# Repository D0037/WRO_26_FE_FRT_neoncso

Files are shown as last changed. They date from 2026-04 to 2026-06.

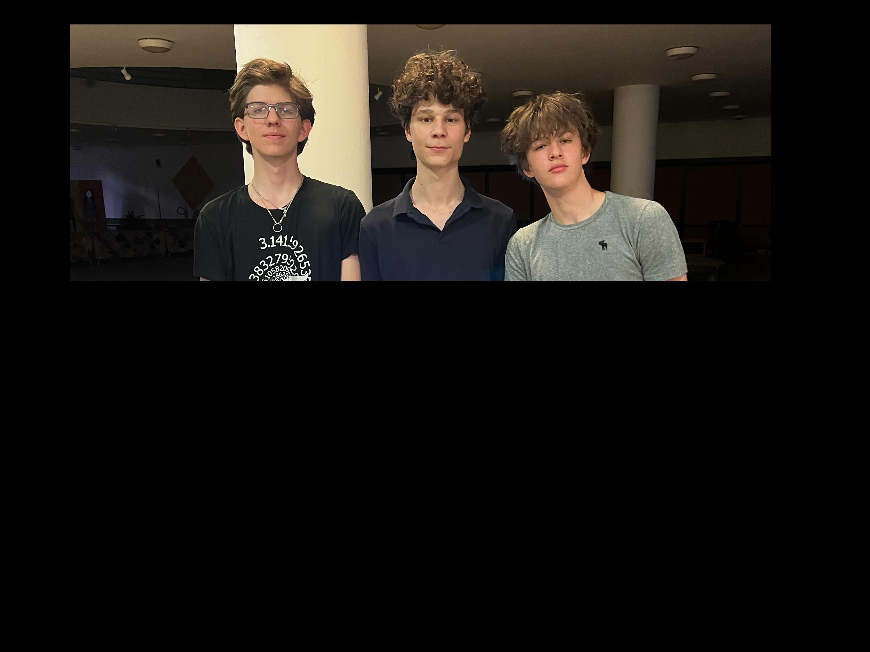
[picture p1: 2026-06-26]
t-photos/Serious.jpg

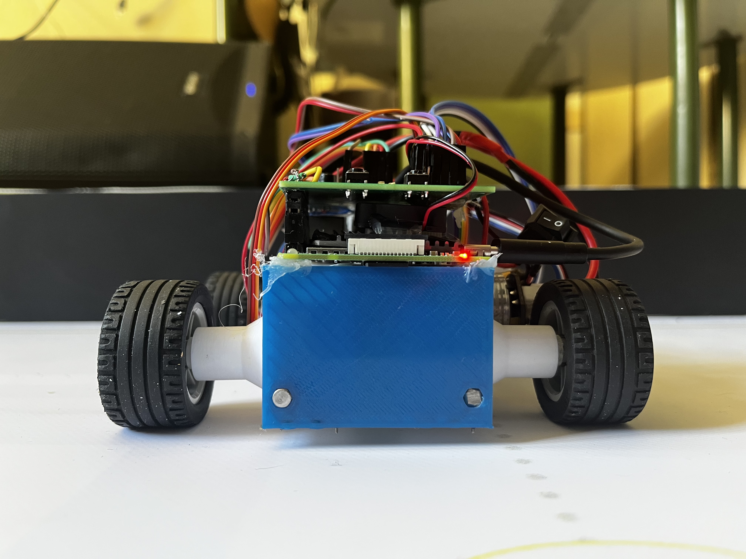
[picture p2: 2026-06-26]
v-photos/back.jpeg

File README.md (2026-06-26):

# FRT Neoncső
## WRO Future Engineers 2026

---

# Team Information

## Team Details

| Item | Information |
|---|---|
| Team Name | FRT Neoncső |
| Country | Hungary |
| School | Budapest Fazekas Mihály Practising Primary and Secondary School |
| Coach | Sásdi Mariann |

## Team Members

| Role | Name | Age |
|---|---|---:|
| Software, electronics, 3D design | Márton Serényi | 16 |
| 3D design, documentation | Ivan Probojcsevity | 16 |
| Software, hardware | Levente Zempléni | 16 |

---

# Project Overview

This project focuses on designing, building, and programming an autonomous vehicle capable of completing the complex challenges of the WRO Future Engineers category.

Team FRT was driven by the challenge of translating engineering principles and problem-solving into practice, and of building a reliable, predictable system in a competition environment full of uncertain variables. Throughout development we followed a systematic process: brainstorming, research, prototyping, testing, and iteration.

_neoncso_ is a **Raspberry Pi**–based, rear-wheel-drive vehicle with Ackermann steering and encoder-based odometry. Its navigation relies on two complementary sensing layers: an **inertial measurement unit (IMU)** holds the heading through a PID controller, three **VL53L1X ToF sensors** measure the distance to the walls, and a **camera** identifies the red and green traffic markers and the parking zone using OpenCV-based HSV color detection.

The control software is built in a modular Python architecture, with separate state machines for the open and obstacle challenges, and a custom web-based HSV calibration tool that lets us quickly retune the vision system to the venue's changing lighting conditions on site.

Our goal is to create an intelligent vehicle that navigates the course reliably, precisely, and quickly, while keeping every decision it makes engineering-based and justifiable.

## Challenge Summary

### 1. Open Challenge

**Goal:** Drive an autonomous car around the track for **3 complete laps** as quickly and accurately as possible. 

Key points:

* No traffic-sign obstacles are placed on the track.
* The track layout changes between rounds because the inner walls can be arranged differently.
* The starting position and driving direction (clockwise or counterclockwise) are randomized.
* The vehicle must:

  * Follow the correct driving direction.
  * Complete 3 laps.
  * Stop in the designated finish section. 
What is tested:

* Lane following
* Cornering accuracy
* Speed and consistency
* Adaptation to changing track layouts

---

### 2. Obstacle Challenge

**Goal:** Complete the same **3 autonomous laps**, but now obey traffic signs and finish with a parking maneuver. 

Additional elements:

* **Red pillar:** pass it on the **right** side.
* **Green pillar:** pass it on the **left** side.
* Traffic signs are placed randomly before each round.
* After finishing the 3 laps, the vehicle must locate the parking area and perform **parallel parking**. 

Scoring rewards:

* Completing laps.
* Not moving traffic signs.
* Starting from the parking lot (optional bonus).
* Successfully parking fully inside the parking area and parallel to the wall. 

What is tested:

* Traffic-sign recognition and decision making.
* Path planning around obstacles.
* Precision vehicle control.
* Autonomous parking.

#### In one sentence

* **Open Challenge:** “Drive 3 laps on a changing track.”
* **Obstacle Challenge:** “Drive 3 laps while obeying red/green traffic signs, then parallel park.”

## Design Philosophy

Our main goal was to make the robot as **size-efficient** as possible. This meant designing the robot to be compact, while still keeping all important functions, such as steering, driving, sensing, and computing, fully usable and reliable.

We chose a smaller design because we realized that several factors are difficult to control perfectly during movement. These include wheel slipping, small inaccuracies in sensor readings, mechanical play in the steering system, and minor errors in motor movement. In a larger robot, these small errors can have a bigger effect on navigation, because the robot needs more space to turn, correct its path, or avoid obstacles.

By making the robot smaller, we increased its tolerance for navigation errors. A compact robot can fit through tighter spaces, make sharper turns, and recover more easily from small positioning mistakes. For example, if the robot slightly misjudges its position or direction, the error is less likely to cause a collision or a major path deviation because the robot takes up less physical space.

This approach also helped reduce the effect of uncontrolled external factors. Wheel slip, for example, can slightly change the robot’s real position compared to what the software expects. Sensor inaccuracies can also cause the robot to detect lines, walls, or objects a little earlier or later than ideal. With a smaller chassis, these small differences are less likely to become serious problems, because the robot has more usable space around it during navigation.

However, making the robot smaller also created new design challenges. All components had to be arranged very carefully, and there was less room for wiring, mounts, gears, sensors, and the onboard computer. Because of this, our design had to balance compactness with functionality. We did not want to make the robot small at the cost of reliability, so every component had to be placed in a logical and space-efficient way.

Overall, our main design philosophy was to create a robot that is compact, precise, and forgiving. By reducing the size of the robot, we made it easier to navigate in uncertain conditions, while still keeping the mechanical and electronic systems strong enough to perform reliably.

---

# Mechanical Design

| Measurement | Value | Unit |
| --- | ----- | ---- |
| Height | 105 | mm |
| Length | 145 | mm |
| Width | 150 | mm |
| Weight | 448 | g |

Our main design goal was to make the robot as compact as possible while compromising as little as possible on functionality, stability, and reliability. This meant that every part of the robot had to be designed with a clear purpose. Instead of simply making the robot smaller, we focused on using the available space efficiently, so the drivetrain, steering system, sensors, and onboard computer could all fit together without interfering with each other.

A smaller robot has several advantages: it is lighter, easier to maneuver, and can react faster in tight spaces. However, making the robot small also creates challenges. Components become harder to mount, wiring becomes more cramped, and mechanical tolerances become much more important. Because of this, the design process required many iterations and careful planning.

## Chassis

For the chassis, we wanted to create something different from a standard flat plate design. Instead of using a large base plate, we built the structure around two parallel metal rods. These rods act as the main frame of the robot and provide a strong, lightweight foundation for the rest of the components.

The main advantage of this design is modularity. Since the rods run through the robot, different components can be mounted onto them using custom-designed brackets. This makes the robot easier to modify, repair, and improve. If a part needs to be moved or redesigned, we do not need to rebuild the entire chassis; we can simply change the mounting piece.

The rods also help keep the robot rigid. A rigid chassis is important because any bending or twisting can affect steering accuracy, gear alignment, and sensor readings. By using metal rods as the main structural element, the robot can stay strong while still remaining compact.

## Mounting

The mounting system was one of the most important parts of the mechanical design. Since the chassis is based on two parallel rods, every major component needed a specialized mount. These mounts had to hold the parts securely while also keeping them in the correct position relative to each other.

We first designed the steering system because it determines the position of the front wheels and takes up a fixed amount of space. At the same time, we considered the size of the onboard computer, the Raspberry Pi. These two parts — the steering system and the Raspberry Pi — helped determine the distance between the two metal rods.

After this, we started designing the drivetrain. This was more difficult because the motor, gears, differential, driveshaft, and rear wheels all had to line up correctly. Even a small misalignment could cause friction, poor power transfer, or gear skipping.

In the final version, we created separate sensor mounts and a combined mount for the Raspberry Pi. The sensor mounts are designed to keep the sensors stable and pointed in the correct direction. This is important because inaccurate sensor positioning can lead to unreliable data and poor robot behavior. The Raspberry Pi mount was designed to keep the computer secure while still allowing access to ports and cables.

## Steering System

The robot uses an Ackermann steering system. This is the same basic steering principle used in many cars. The main idea behind Ackermann steering is that the two front wheels do not turn at the same angle during a corner.

When a vehicle turns, the inner wheel follows a smaller circle than the outer wheel. Because of this, the inner wheel needs to turn more sharply, while the outer wheel turns at a smaller angle. If both wheels turned at the same angle, one or both wheels would slide sideways instead of rolling smoothly.

Ackermann steering reduces this slipping by making the wheel angles match the natural turning path of the robot. This improves control, reduces energy loss, and makes turning smoother. It is especially useful in tight turns, where the difference between the inner and outer wheel paths becomes more noticeable.

We chose Ackermann steering because it gives the robot more predictable movement. Instead of relying on wheel slipping or skid steering, the robot can turn in a more controlled and efficient way. This also reduces stress on the drivetrain and makes the robot easier to control through software.

## Drivetrain

The drivetrain is responsible for transferring power from the motor to the wheels. Our robot is rear-wheel driven and front-wheel steered. This means the rear wheels push the robot forward, while the front wheels control the direction.

We designed a custom drivetrain based on our previous experience with similar systems. The drivetrain uses a motor, a differential gearset taken from an RC car, custom-designed gears, and a main driveshaft system.

The motor provides rotational motion, but the raw output of the motor is not always directly suitable for driving the wheels. Motors usually spin very fast but may not produce enough torque on their own. Because of this, gears are needed to adjust the balance between speed and torque.

A gear ratio describes how much the gears change the motor’s output. A higher gear reduction increases torque but reduces speed. A lower gear reduction keeps more speed but provides less torque. Finding the correct gear ratio was important because the robot needed enough torque to move reliably, but still enough speed to perform well.

Our final gear ratio is approximately 1:6, using a three-gear reduction. At first, we tested a 1:1.5 reduction, but our torque calculations were too optimistic and the motor could not start the robot reliably without a small push. Because of this, we redesigned the drivetrain with a stronger reduction. This increased usable torque at the wheels and also reduced the top speed, which made it easier to brake before corners and control the robot more accurately. 

Our exact torque numbers are:

Motor wattage = Voltage * Amperage

Torque = Wattage/(2πF) =

Voltage = 6.4V

Amperage =

F = base rpm*(voltage/recomended voltage)=20500*(6.4/12)=10933 rpm

Torque at the wheels = torque*6

## Design Iterations

During the design process, we encountered many problems that required multiple iterations. Our first focus was the driving mechanism. At the beginning, the basic concept worked, but once we started designing the custom differential gearbox holder, most of the mechanical problems appeared.

One of the biggest challenges was that the motor was slightly weaker than we expected. This meant that the first gear setup did not provide enough torque for reliable movement. To solve this, we had to redesign the gear system and adjust the gear ratio. This helped the motor produce more usable force at the wheels.

Another major challenge was part fit. Since many of the components were 3D printed, small measurement errors could cause big problems. In some cases, a difference of only one or two millimeters decided whether the parts fit together or not. Gear spacing, screw holes, rod mounts, and shaft positions all had to be adjusted multiple times.

This taught us that mechanical design is not only about the main idea, but also about the small details. A design can look correct in CAD, but after printing and assembly, problems can still appear. Parts may be too tight, too loose, misaligned, or difficult to assemble.

Through these iterations, we learned the importance of testing and improving the design step by step. Each version helped us understand the robot better. For example, we learned how important gear ratios are in a drivetrain. The gear train must give the motor enough torque to move the robot, but it must also keep enough rotational speed so the robot does not become too slow.

We also learned that compact design requires careful planning. When many components are placed close together, changing one part often affects several others. This meant that the steering, drivetrain, chassis, and electronics could not be designed separately. They had to be developed as one connected system.

---

# Electronics

## Component List

| Component | Purpose | Connection | Voltage | Why we chose it |
| --- | --- | --- | --- | --- |
| Raspberry Pi 4 | Main computer | Camera, I2C, motor control | 5V | Enough processing power for OpenCV |
| Pi Camera 3 Wide | Vision | CSI camera port | Pi powered | Wide field of view |
| MPU6050 | IMU / gyro | I2C | 3.3V/5V module | Heading correction |
| TOF400C / VL53L1X | Wall distance | I2C | 3.3V/5V | Fast short-range distance |
| SG92R-180 servo | Steering | GPIO/PWM | 5V | Easy to use |
| rp385-st/2270/dv motor with encoder | Driveshaft | GPIO/PWM | battery voltage | Easily accesible, powerful |
| 3436343 Amewi battery pack | Power source  | power input | 7.4V | Portable power |

| Name / Part number | Component type |
| --- | --- |
| GY-521 | MPU6050 accelerometer + gyroscope sensor module |
| MBRS540T3G | Schottky diode |
| SPH-2x20P | 2×20 pin header / connector |
| TPS54332DDAR | Step-down / buck voltage regulator IC |
| SMD0603-220R-1% | 220 Ω SMD resistor, 0603 |
| SMD0603-330R-5% | 330 Ω SMD resistor, 0603 |
| SMD0603-1K-5% | 1 kΩ SMD resistor, 0603 |
| SMD0603-4.7K-1% | 4.7 kΩ SMD resistor, 0603 |
| SMD0603-10K-1% | 10 kΩ SMD resistor, 0603 |
| SMD0603-20K-5% | 20 kΩ SMD resistor, 0603 |
| SMD0603-100K-1% | 100 kΩ SMD resistor, 0603 |
| GRM21BR60J226ME39K | 22 µF ceramic SMD capacitor |
| SMD0603-6.8K-5% | 6.8 kΩ SMD resistor, 0603 |
| SMD0603-15K-5% | 15 kΩ SMD resistor, 0603 |
| SMD0603-47R-1% | 47 Ω SMD resistor, 0603 |
| KPT-3216EC | SMD LED, likely red/orange |
| KP-3216 SGD | SMD LED, likely green |
| SMD0603-2.2K-1% | 2.2 kΩ SMD resistor, 0603 |
| HPI0630-2R2 | 2.2 µH power inductor |
| A4950ELJTR-T | DC motor driver IC |
| 100 uF / 16V | Electrolytic or SMD capacitor |
| GCM1885C2A221FA16J | 220 pF ceramic SMD capacitor |
| SMD1206-0.22R-5% | 0.22 Ω current-sense / shunt resistor, 1206 |
| SMD0603-62K-1% | 62 kΩ SMD resistor, 0603 |
| M 2,5 x 6 DF | M2.5 screw |
| M 3 x 12 HBKNY | M3 screw |
| M 3 HTL | M3 threaded insert / spacer / hardware part |
| M 3 OA | M3 washer / nut / hardware part |
| RC-40-10/FF | 40-pin female-female ribbon cable, 10 cm |
| RC-40-20/FF | 40-pin female-female ribbon cable, 20 cm |
| PD-QC-AFC-5-20 | USB-C PD / QC / AFC trigger or power module |
| TACT-65R-F | Tactile push button |
| ST 1/BK (MRS-1) | Black terminal / connector |
| XT30U-M | XT30 male power connector |
| XT30U-F | XT30 female power connector |

## Wiring Diagram

Included in the `schemes/` folder of the repository.

---

## Communication Architecture

The robot uses several communication methods for different parts of the system. These communication methods are important because the robot has to connect sensors, the onboard computer, and development tools in a reliable way.

The main hardware communication protocol used inside the robot is **I²C**. For development and debugging, we used **SSH** to access the Raspberry Pi remotely, and an **HTTP server** for camera and video testing.

---

### I²C Communication

I²C is used for communication between the Raspberry Pi and several sensors.

In our system, I²C is used for sensors such as the gyroscope and the ToF distance sensors. Each device on the I²C bus has its own address, so the Raspberry Pi can request data from the correct sensor.

The main benefit of I²C is that it reduces wiring complexity. Instead of needing separate communication wires for every sensor, several devices can share the same bus. This helped us keep the electronics cleaner and more space-efficient.

---

### SSH for Development and Code Upload

This was useful because we did not need to connect a monitor, keyboard, and mouse to the robot every time we wanted to change the code. We could upload files, run scripts, read errors, and restart programs directly from our development computer.

SSH made testing faster and more practical. Since the robot could stay assembled while we updated the software, we could quickly change code, test the robot, and then adjust the program again if something did not work correctly.

---

### HTTP Server for Video Testing

For camera testing, we used an **HTTP server** to stream video from the robot. This allowed us to view the camera feed in a browser from another device.

This was especially useful for testing the image recognition system. Since the robot relies on camera data to detect colored lines and objects, we needed to see what the robot was actually seeing. The video stream helped us check whether the camera angle, focus, lighting, and color detection were correct.

The HTTP server was also useful for debugging because it made the camera processing visible in real time. Instead of only reading printed values in the terminal, we could visually confirm if the software was detecting the correct areas.

---

### Overall Communication Design

The communication system was designed to keep the robot practical and easy to develop. I²C handles internal sensor communication, SSH handles remote development, and the HTTP server supports camera debugging.

Together, these systems made the robot easier to build, test, and improve. I²C reduced wiring complexity, SSH made code updates faster, and the HTTP video stream helped us understand and tune the camera-based parts of the software.

---

# Sensors

We chose our sensors based on three main priorities: simplicity, reliability, and the ability to combine different kinds of data. Instead of depending on only one sensor type, we wanted the robot to collect information from several independent sources. This is important because every sensor has weaknesses, and no measurement is perfectly accurate in real-world conditions.

Our robot estimates its position and movement using multiple datasets: distance from the walls, color markings on the floor, motor rotation data, steering angle, and readings from the gyroscope and accelerometer. By combining these different measurements, we can reduce the effect of individual sensor errors. This approach is often called sensor fusion, which means using multiple sensor inputs together to create a more accurate understanding of the robot’s position and movement.

For example, motor rotation data can estimate how far the robot has travelled, but it can become inaccurate if the wheels slip. Distance sensors can measure how far the robot is from the walls, but they may be affected by surface angle or reflections. A camera can recognize floor markings and track features, but lighting conditions can influence image processing. The gyroscope can detect changes in rotation, but it may drift over time. By comparing these different sources, the robot can identify when one measurement is unreliable and correct its behavior using the others.

This gives the robot a much better tolerance for imperfect measurements. If one sensor gives a slightly incorrect value, the system does not immediately lose track of its position. Instead, the robot can cross-check the data with other sensors and make a more stable decision. This makes navigation more reliable, especially in a competition environment where lighting, friction, surface quality, and positioning are never perfectly controlled.

Using different datasets also helps us understand the robot’s movement from different perspectives. The camera gives visual information, the ToF sensor gives distance information, the MPU6050 gives motion and orientation data, and the motor drivers give mechanical movement data. Together, these create a more complete picture of what the robot is doing and where it is on the track.

## Camera System
The robot uses a Pi Camera 3 Wide, which is one of the most important sensors in our system. Its wide field of view allows the robot to see more of its surroundings at once. This is especially useful because the robot can detect lines, floor markings, obstacles, and nearby objects without needing to physically move the camera.

Compared to a standard narrow-angle camera, the wide camera gives better environmental awareness. A narrow camera may provide a more focused image, but it sees a smaller area. For our robot, seeing more of the track is more useful than seeing a small area in extreme detail. The wider view helps the robot react earlier and gives the software more visual information to work with.

The camera is also small and lightweight, which makes it suitable for a compact robot. Since our design focuses heavily on size efficiency, we needed sensors that would not take up too much space or add unnecessary weight.

Another major advantage is that the Pi Camera 3 Wide is designed to work with Raspberry Pi systems. This makes integration easier because it has good software support, low latency, and strong compatibility with the Raspberry Pi 4. Low latency is especially important for real-time vision tasks because the robot needs to react quickly to what it sees.

The camera data is mainly used for visual navigation. It helps us to detect the colored lines on the floor, track the boundaries of the marker blocks. However, camera data can be affected by lighting conditions, shadows, motion blur, and reflections. This is why we do not rely only on the camera. Instead, its data is combined with other sensors to make the robot’s decisions more reliable.

## Gyroscope
We chose the MPU6050 sensor because it is simple, accessible, well-documented, and familiar to us. Since it is widely used in robotics projects, there are many examples, libraries, and resources available. This made it easier to integrate into our system and reduced the risk of spending too much time solving basic communication problems.

The MPU6050 includes both a gyroscope and an accelerometer. The gyroscope measures rotational movement, while the accelerometer measures acceleration along different axes. Because the sensor can measure motion in three axes, it can provide useful information about how the robot moves and turns.

The gyroscope is especially useful for detecting changes in direction. For example, when the robot turns, the gyroscope can measure the rotation and help estimate the robot’s heading. This is important because the robot needs to know not only where it is, but also which direction it is facing. The accelerometer measures changes in speed and movement direction. In theory, acceleration data can help estimate movement, but in practice it can be noisy and affected by vibration. Because of this, we use it mainly as supporting data rather than as the only source of position information.

One important concept with this sensor is drift. Drift means that small errors build up over time, causing the measured angle or position to slowly become inaccurate. This is a common issue with gyroscopes. To reduce this problem, we use a custom calibration algorithm. When the robot starts a round, it takes a large sample of gyroscope measurements while standing still, calculates the average offset, and subtracts this offset from later measurements. This gives the program more reliable heading data.

## ToF Sensors

We chose the ToF400C because it is easy to work with, accurate enough for our needs, and simpler than a full LiDAR system. A ToF sensor measures distance by sending out light and measuring how long it takes for the reflection to return. This allows it to estimate how far away an object or wall is. The ToF400C uses light-based measurement, which makes it better suited for compact robotic navigation where quick and accurate distance readings are useful.
Compared to ultrasonic sensors, ToF sensors are often more precise and faster at short distances. Compared to LiDAR, the ToF400C is much simpler. A LiDAR system can provide much more detailed mapping data, but it is also more expensive, more complex, and harder to process. For our robot, we did not need a full 3D or 2D map of the environment. We mainly needed reliable distance readings that could be processed by a simple algorithm.

The ToF400C provides an easily understandable type of data: distance. This makes it practical for decision-making. For example, if the robot knows how far it is from the left or right wall, it can estimate its position inside the track and correct its path if it gets too close to one side.

However, ToF sensors can still have imperfections. Their measurements may be affected by reflective surfaces, dark surfaces, transparent materials, or unusual angles. This is another reason why we combine ToF data with camera, motor, and gyroscope data instead of relying on it alone.

## Additional Sensors

Although the motors are not traditional sensors, their position feedback gives us another important dataset. Because the motor drivers allow us to know the motor position or rotation, we can calculate approximately how far the robot has travelled.

This method is often called odometry. Odometry estimates movement based on wheel rotation. If we know the wheel diameter and how much the motor has rotated, we can calculate the distance travelled in centimeters. This is useful because it gives the robot a continuous estimate of its movement, even when visual or distance data is temporarily unreliable.

By also tracking the steering angle, we can estimate the path the robot has taken. If the robot moves forward while the wheels are turned, it follows a curved path. By combining travelled distance with steering angle, we can create an approximate layout of the robot’s journey. This helps estimate the robot’s position on the track.

However, odometry also has weaknesses. If the wheels slip, the motor may rotate even though the robot does not move the expected distance. Small errors in wheel diameter, gear ratios, or steering angle can also build up over time. Because of this, odometry is useful, but it should not be the only navigation method.

## Power System

The robot is powered by a 7.4V Amewi battery pack, which provides the main energy source for the drive motor and the onboard electronics. Because the Raspberry Pi, sensors, servo, and logic-level electronics require stable low-voltage power, the battery voltage is converted to a regulated 5V supply using a buck converter circuit based on the TPS54332 regulator. This stable 5V rail is important because the Raspberry Pi is sensitive to voltage drops, especially while processing camera data and controlling multiple sensors at the same time.

The drive motor is one of the largest power consumers in the robot, so it is controlled through the motor driver instead of being connected directly to the Raspberry Pi. This protects the controller and allows the software to control motor speed and direction safely. All electronic parts share a common ground, which is necessary so that PWM, GPIO, I²C, and sensor signals have the same voltage reference.

During testing, we found that power stability and thermal stability are closely connected. Long motor and battery tests caused the Raspberry Pi to overheat when the cooling system was removed, so we added a fan and cooling board. This made the robot more reliable during longer runs and reduced the chance of crashes, throttling, or camera connection problems during the challenge.

---

# Software Architecture

## Software Overview

The robot’s software is built as a modular Python-based control system running on the Raspberry Pi. Its purpose is to read sensor data, process camera input, control the drive motor and steering servo, and make real-time navigation decisions during the WRO Future Engineers challenges.

The architecture separates the main challenge logic from the lower-level hardware control modules. This makes the code easier to test, debug, and improve, because sensors, movement, image processing, and logging are each handled in their own files. The main program can therefore focus on decision-making, while the utility modules handle direct communication with the electronic components.

The software is designed around continuous feedback. The robot constantly reads its gyroscope, ToF distance sensors, motor encoder, and camera image. These inputs are used to correct the steering angle, maintain direction, detect walls or obstacles, and follow the correct path during the challenge. Debugging tools such as logging and live video streaming are also included, which helped during testing and calibration.

## Repository Structure

The repository follows the standard WRO engineering documentation structure.

* `src/` contains the robot control software.
* `src/open.py` contains the main program for the open challenge.
* `src/obstacle.py` is reserved for the obstacle challenge logic.
* `src/config.py` stores shared configuration values, GPIO pins, sensor addresses, HSV color filters, thresholds, and tuning constants.
* `src/test.py` contains testing functions for individual subsystems such as ToF sensors, camera processing, encoders, and movement.
* `src/requirements.txt` lists the Python libraries needed to run the software.
* `src/utils/` contains reusable helper modules for hardware and debugging.
* `src/utils/gyro.py` handles gyroscope and accelerometer readings.
* `src/utils/tof.py` handles the VL53L1X time-of-flight distance sensors.
* `src/utils/movement.py` controls the motor, steering servo, and encoder-based movement.
* `src/utils/image_proc.py` handles camera capture and computer vision processing.
* `src/utils/stream.py` provides a Flask-based live camera/debug stream.
* `src/utils/log.py` provides file and console logging.
* `models/` stores 3D-printable or manufacturable model files.
* `schemes/` stores wiring and electronic diagrams.
* `v-photos/` and `t-photos/` store vehicle and team photos.
* `video/` stores the driving demonstration video link.
* `other/` stores extra technical documentation and supporting files.

This structure keeps the engineering documentation and the robot software in one place, while still separating code, models, diagrams, photos, and videos clearly.

## Module Description

### `open.py`

`open.py` is the main control file for the open challenge. It initializes the GPIO system, movement module, ToF sensors, camera module, and gyroscope. After setup, it enters the main driving loop.

Inside the loop, the robot reads distance values from the ToF sensors and heading data from the gyroscope. It calculates the difference between the target heading and the current heading, then uses this error to correct the steering. The steering correction uses proportional and derivative-style feedback so that the robot can keep a stable direction instead of constantly overcorrecting.

The file also includes constants for speed, steering center, steering direction, heading correction, and centering correction. These values can be tuned during testing to make the robot drive more smoothly.

### `config.py`

`config.py` acts as the central configuration file of the robot. It contains values that are used by multiple modules, including GPIO pin numbers, I²C addresses, logging settings, motor encoder conversion factors, ToF timing values, and HSV color filters.

Keeping these values in one file makes calibration easier. For example, if a sensor pin, color threshold, or motor parameter changes, it can be adjusted in `config.py` without rewriting the whole program.

### `utils/gyro.py`

The gyroscope module communicates with the MPU6050 sensor through I²C using SMBus. It reads raw gyroscope and accelerometer values, converts them using scale factors, and calculates the robot’s rotation around the Z axis.

A separate background thread continuously updates the current heading value. At startup, the gyroscope is calibrated by taking many samples and calculating an offset. This reduces drift and improves the accuracy of the heading correction.

The module provides functions for resetting the heading, reading the current angle, reading raw gyroscope values, reading accelerometer values, and safely stopping the background thread.

### `utils/tof.py`

The ToF module manages three VL53L1X distance sensors: front, left, and right. Since these sensors normally share the same default I²C address, the software uses their XSHUT pins to start them one by one and assign separate addresses.

After setup, the module continuously polls the sensors in a background thread. The latest valid distances are stored in a shared dictionary and can be accessed through simple functions such as `get_front()`, `get_left()`, and `get_right()`.

This module is important for wall detection, centering, and obstacle awareness. It allows the main program to quickly access distance data without blocking the rest of the robot’s control loop.

### `utils/movement.py`

The movement module controls the drive motor, steering servo, and motor encoder. It uses Raspberry Pi GPIO pins for motor direction and PWM control, and hardware PWM for the steering servo.

The module provides functions to set the steering angle, set motor speed, read encoder position, estimate speed, and move a given distance. The encoder interrupt callback updates the position counter whenever the encoder signal changes.

The `move()` function also includes a basic PID-style correction system. It uses the gyroscope heading to keep the robot moving straight while travelling a target distance.

### `utils/image_proc.py`

The image processing module handles camera capture using the Raspberry Pi camera. It captures frames in a separate thread, rotates the frame, applies preprocessing, and stores the latest image for use by other parts of the program.

It uses OpenCV and HSV color filtering to detect colored features. The `get_direction()` function detects orange and blue line regions and compares their positions to decide which direction is indicated. The `get_blocks()` function detects red and green blocks by applying HSV filters, contour detection, and area filtering.

The module also removes irrelevant parts of the image using black wall/line masking. This helps reduce noise and makes the vision system focus on the useful part of the camera frame.

### `utils/stream.py`

The stream module provides a live debugging stream using Flask. Other modules can send frames to it with `stream.show(name, frame)`, and the stream server makes these frames viewable over the network.

This is useful during development because the team can see what the robot camera sees and how the processed debug image looks. It makes it much easier to tune HSV filters, check line detection, and understand camera-based errors.

### `utils/log.py`

The logging module writes timestamped messages to both the console and a log file. It supports different log levels such as debug, info, warning, and error.

Logging is useful during testing because it records sensor values, detected events, warnings, and movement behavior. This makes it easier to find problems after a test run and compare different software versions.

### `test.py`

`test.py` contains small test routines for checking individual components. It can be used to test ToF distance readings, image processing, motor encoder readings, and movement behavior.

This file is important because the robot has many connected subsystems. Testing them separately helps identify whether a problem comes from the software, wiring, sensor calibration, or mechanical design.

## Program Flow

The program starts by importing the configuration file and the utility modules. Then it initializes the Raspberry Pi GPIO mode and sets up the hardware systems.

First, the movement module is prepared, including the motor PWM, servo PWM, and encoder input. Next, the ToF sensors are initialized and assigned their separate I²C addresses. The camera system is started in the background, and the gyroscope is calibrated and reset.

After setup, the robot enters its main control loop. In this loop, the robot repeatedly reads the ToF sensors and the gyroscope. The gyroscope gives the current heading, while the ToF sensors provide distance information from the front, left, and right sides.

The software then calculates the heading error by comparing the current heading with the target heading. A steering value is calculated from this error. The proportional part reacts to how far the robot is from the target angle, while the derivative part reacts to how quickly the robot is rotating. This helps the robot correct its direction smoothly.

If side distance data is available, the software also applies a centering correction. This compares the left and right distance sensor values and adjusts the steering so the robot can stay more centered between walls.

Finally, the movement module applies the calculated steering angle and sets the motor speed. This loop continues until the challenge logic decides that the required number of corners or sections has been completed. On interruption or shutdown, the program stops the gyroscope thread, camera thread, motor PWM, servo PWM, and GPIO outputs safely.

## Sensor Processing

The robot uses multiple sensors because no single sensor gives enough information for reliable autonomous driving. Each sensor type has a different role in the software architecture.

The gyroscope is used for heading estimation. It measures angular velocity around the Z axis, and the software integrates this value over time to estimate the robot’s current rotation. Before driving, the gyroscope is calibrated to reduce drift. During movement, the heading value is used for steering correction, allowing the robot to maintain a stable direction even if the floor, motor power, or mechanical friction causes small deviations.

The ToF sensors measure distance to nearby objects and walls. The front sensor is used to detect objects or approaching walls, while the left and right sensors help the robot understand its position inside the track. The software reads these sensors continuously in a background thread, so the main program always has access to the most recent valid distance values. This makes the robot more responsive and prevents sensor reading delays from slowing down the driving loop.

The camera is used for visual detection. The image processing system converts the camera image into HSV color space, which makes it easier to isolate specific colors under changing lighting conditions. HSV filters are used to detect orange, blue, red, and green objects or lines. Morphological operations such as erosion and dilation reduce noise, and contour filtering removes small false detections.

For line direction detection, the software compares the detected position of orange and blue regions. Depending on which color appears lower or more relevant in the frame, the function returns a direction decision. For block detection, red and green masks are processed with contour detection, and the software calculates the center point and area of each detected block.

The motor encoder is used for position feedback. It counts wheel or motor movement through GPIO interrupts, and the software converts encoder ticks into travelled distance using a conversion factor. This makes distance-based movement possible and also allows testing of motor behavior.

All sensor processing is connected through the main control loop. The gyroscope provides orientation, ToF sensors provide distance, the camera provides visual interpretation, and the encoder provides movement feedback. By combining these inputs, the robot can drive more accurately than it could with only one sensor.

---

# Navigation

## Line Following

The robot uses a camera-based navigation system to detect colored lines and visual markers on the field. The Pi Camera captures live video frames, which are processed using OpenCV. The image is converted into HSV color space, because HSV filtering is more reliable for detecting colors under changing lighting conditions than using raw RGB values.

The software contains predefined HSV ranges for orange, blue, red, green, and magenta colors. These thresholds are stored in the configuration file, so they can be tuned without rewriting the full vision algorithm. During processing, the image is filtered by color, and the resulting masks are cleaned with erosion and dilation. This removes small noise and makes the detected line areas more stable.

For line detection, the robot mainly compares orange and blue regions. The image processing module finds the visible colored areas, calculates their average position, and then decides which line is currently dominant. If the orange region appears lower or more relevant in the image than the blue region, the function returns one direction; if the blue region is more dominant, it returns the opposite direction.

This allows the robot to recognize the direction of the track or turn markers. Instead of following a simple black line, the robot uses color-based interpretation to understand which way it should continue. The camera system also includes a preprocessing step that masks out irrelevant parts of the frame above the detected black wall or dark boundary. This helps the algorithm focus on the useful lower part of the image and reduces false detections.

The line-following system is supported by the gyroscope. While the camera gives visual direction information, the gyroscope helps the robot keep a stable heading. This combination makes the navigation more accurate than relying only on the camera, because the robot can still maintain direction even when the camera frame is temporarily unclear.

## Obstacle Detection

Obstacle detection is handled by two main sensor systems: the Time-of-Flight distance sensors and the camera.

The ToF sensors measure the distance between the robot and nearby walls or objects. The robot uses front, left, and right distance readings to understand its surroundings. The front sensor is used to detect objects or walls in front of the robot, while the side sensors help estimate how centered the robot is inside the track.

The ToF module initializes the VL53L1X sensors using their XSHUT pins. Since these sensors normally use the same default I²C address, the software starts them one by one and assigns them separate addresses. After initialization, the sensors are read continuously in a background thread. This means the main driving program can access the most recent distance values without waiting for a slow sensor reading.

The camera also contributes to obstacle detection by identifying colored blocks. The image processing module filters the camera frame for red and green colors, then uses contour detection to locate block-shaped objects. Small contours are removed using an area threshold, so random noise is ignored. For each detected block, the software calculates its center point and visible area.

Red and green blocks are important because they are not just obstacles; they also tell the robot which side to pass on. The block color and position help the software decide the avoidance direction. A larger detected area usually means that the block is closer or more important, while the center position tells whether it is on the left, right, or middle of the camera view.

By combining ToF distance data with camera-based color recognition, the robot can detect both physical distance and visual obstacle type. This gives the navigation system more information than a single sensor could provide.

## Obstacle Avoidance

Obstacle avoidance is based on steering decisions made from sensor feedback. The robot uses Ackermann steering, meaning it behaves more like a real car than a tank-drive robot. Because of this, obstacle avoidance must be smooth and planned; the robot cannot simply rotate in place.

The first layer of avoidance comes from the ToF sensors. If the front distance becomes too small, the robot knows that something is in front of it and must react. The side sensors help decide which side has more free space. If the left side has more distance than the right side, the robot can steer left; if the right side has more distance, it can steer right.

The second layer of avoidance comes from the camera. When the camera detects a red or green block, the robot can use the block’s color and position to choose a passing direction. The detected contour center tells the robot where the obstacle appears in the camera image. The visible area of the contour helps estimate how close or important the obstacle is.

The steering correction is also influenced by the gyroscope. The open challenge code calculates a heading error by comparing the target angle with the current gyro angle. A proportional term reacts to the size of the heading error, while a derivative-style term uses angular velocity to reduce overcorrection. This allows the robot to steer around obstacles while still keeping its movement stable.

Side-distance correction is also used to keep the robot centered. The software compares the left and right ToF values and adds a centering correction to the steering angle. This helps the robot avoid drifting too close to one wall while driving through the track.

The motor and steering are controlled separately. The drive motor sets the forward speed, while the steering servo sets the angle of the wheels. This separation allows the robot to slow down, turn, correct its direction, and then continue forward smoothly after passing an obstacle.

## Recovery Strategies

Recovery strategies are important because real-world robot movement is never perfect. The robot may face unclear camera images, sensor noise, wrong detections, wheel slip, or unexpected contact with walls or obstacles. The software architecture includes several ways to reduce these problems.

The first recovery method is gyro-based heading correction. If the robot starts turning too far away from its intended direction, the gyroscope detects the change in angle. The steering system then applies a correction to return the robot closer to the target heading. This helps the robot recover from small mechanical errors, uneven motor power, or slight impacts.

The second recovery method is ToF-based centering. If the robot gets too close to one side of the track, the side distance sensors detect the imbalance. The steering correction then pushes the robot back toward the center. This is especially useful after turns or obstacle avoidance maneuvers, where the robot may not be perfectly aligned.

The third recovery method is camera noise filtering. The vision system does not directly trust every colored pixel. It uses HSV filtering, erosion, dilation, contour filtering, and area thresholds to remove small false detections. This prevents the robot from reacting to random reflections, shadows, or tiny colored objects that are not relevant to navigation.

The fourth recovery method is continuous sensor updating. The camera, gyroscope, and ToF sensors are updated continuously or in background threads. This means the robot does not depend on a single reading. If one frame or one distance value is wrong, the next readings can correct the decision quickly.

The fifth recovery method is safe cleanup. If the program is interrupted, the software stops the gyro thread, camera thread, motor output, steering output, and GPIO system. This prevents the robot from continuing to drive uncontrollably after a software stop or testing interruption.

Possible future recovery improvements could include a stuck-detection system using the motor encoder, automatic reverse movement when the front ToF sensor detects a very close obstacle, and a “search mode” when no valid line or block is visible for several frames. These additions would make the robot even more reliable during difficult runs.

---

# Control Systems

The robot’s control system is based on sensor feedback. This means the robot does not simply follow fixed movements, but constantly reacts to what the sensors detect.

The most important control inputs are the ToF distance sensors and the camera system. The ToF sensors detect changes in distance from walls or obstacles. If the robot notices that a wall is ending, getting too close, or suddenly changing distance, it can decide to turn, correct its path, or stop.

The camera is the second major decision-making input. It uses color and image recognition to detect track markings and obstacles. This allows the robot to react not only to distances, but also to visual information, such as colored lines or colored blocks.

Using both distance-based and camera-based control makes the robot more reliable. The ToF sensors give simple and fast distance data, while the camera gives more detailed information about the track and objects.

## Steering Control

The steering control is designed to be simple and predictable. During the open challenge, the robot mainly decides when and where to turn based on wall detection and colored line detection.

If a ToF sensor detects that a wall has ended or disappeared, the robot interprets this as a possible corner or turning point. At the same time, the camera checks for colored lines on the track. The robot uses the first detected line and the first wall disappearance to decide whether it should follow a clockwise or counter-clockwise route.

This allows the robot to choose the correct turning direction automatically instead of relying on a fully pre-programmed path.

During the obstacle challenge, steering decisions are mainly based on camera recognition. The camera detects the color and position of obstacles, and the robot uses this information to decide how to steer around them.

Important concepts:

- **ToF-based steering:** the robot uses distance changes to decide when to turn.
- **Camera-based steering:** the robot uses visual information, such as colored lines or blocks, to choose direction.
- **Clockwise and counter-clockwise navigation:** the robot identifies whether it should follow the track by turning mostly right or mostly left.
- **Feedback control:** the steering is adjusted using live sensor data instead of fixed timing.

## Speed Control

The robot mostly uses a constant driving speed while moving. This makes the control system simpler and more predictable, because the robot does not need to constantly calculate different speed levels during normal driving.

During turns, the rear differential helps balance the speed difference between the two rear wheels. This is important because when the robot turns, the outer wheel travels a longer path than the inner wheel. The differential allows the wheels to rotate at different speeds, which reduces slipping and makes turning smoother. The robot also reduces its motor speed during turns.

Even though the speed is mostly constant, the robot can still stop or slow down when needed. For example, if the ToF sensors detect an obstacle or an unexpected wall distance, the control system can react by stopping the robot or preparing for a turn.

Important concepts:

- **Constant speed:** makes movement easier to control and tune.
- **Differential gearset:** allows the rear wheels to rotate at different speeds during turns.
- **Wheel slip reduction:** improves stability and efficiency.
- **Sensor-triggered stopping:** allows the robot to react when an object or wall is too close.
---

# Testing

We performed tests on most major components, including the motors, batteries, drivetrain, cooling system, sensors, and software. Our goal was not only to check whether each part worked, but also to see how it behaved under less ideal conditions.

We also tried to calculate everything that could be calculated before building. This included gear ratios, clearances, expected movement distances, sensor positions, and mechanical tolerances. We followed manufacturer data wherever possible, especially for electronic components, sensors, motors, and batteries.

## Test Methodology

Our testing method was based on two main ideas: testing components separately and then testing them inside the complete system.

First, we tested individual parts to make sure they worked on their own. This made it easier to find problems because we could focus on one component at a time. After that, we tested the same parts again after assembling them into the full robot. This was important because a component can work alone, but still cause problems when placed inside the final system.

We also tried to simulate harsher conditions than normal. These included high temperature, reduced battery voltage, worse lubrication, and traction loss. This helped us check whether the robot could still function if the environment was not ideal.

For example, we tested the motors and batteries in the main hall of our school, where the temperature was around 35°C. We wrote a simple test program that continuously ran the motors until the battery drained. This allowed us to test battery life, motor heating, and general reliability.

We repeated a similar test after the electronics were fully assembled. The first result was not ideal because we had removed the full cooling system from the Raspberry Pi 4. During the test, the Raspberry Pi constantly overheated, so we had to assemble a fan and cooling board for the CPU. After improving the cooling, the system became more reliable.

For 3D-printed parts, we generally used a tolerance of around 0.2 mm. In some cases, this was not enough because printed parts do not always come out exactly as designed. Small errors in printing, material shrinkage, or assembly alignment could cause parts to fit too tightly or too loosely. When this happened, we adjusted the parts manually using grinding and filing, or redesigned the part when needed.

## Mechanical Testing

Mechanical testing focused mainly on the drivetrain, gears, driveshaft, tires, and lubrication. Since several drivetrain parts were 3D printed, we wanted to make sure they could survive longer operation without breaking, slipping, or overheating.

One important test compared two types of lubrication for the driveshaft: WD-40 and lithium grease. The goal was to see which one reduced friction better and helped the drivetrain run more smoothly. In the end, we chose the lithium grease, because it was easier to apply, and it stayed on much longer.

This test was also a durability test for the gears and the 3D-printed driveshaft. At first, we did not fully trust the strength of the printed drivetrain parts, especially under continuous load. However, the system performed much better than expected and survived the test successfully.

We also tested tire slip by putting a small amount of water on the wheels. This simulated a low-traction situation where the wheels could lose grip. The robot was still able to function, but it performed much better under normal dry conditions.

This confirmed that the drivetrain works, but it also showed that traction is very important for accurate navigation. If the wheels slip, the robot may travel less than expected even though the motors are rotating. This can affect odometry and turning accuracy. We try to correct this using sensor feedback, but wheel slip can still create problems. During normal laps, without external effects on the drivetrain, the robot and software perform reliably.

## Sensor Testing

Sensor testing was done to improve the accuracy and reliability of the robot’s measurements. Since our navigation depends heavily on sensor data, even small sensor errors can affect movement decisions.

We tested the accuracy of the ToF sensors under different lighting conditions. They were least accurate in direct sunlight and most stable under indoor LED lighting. During normal tests with known distances, the readings stayed within our acceptable error range, so we did not add additional software correction. To reduce gyroscope drift, we calibrate the gyroscope at every startup.

## Software Testing

Software testing was done by testing each module separately before using it in the full robot program. This helped us find problems faster and made debugging easier.

We tested the motor control code by running the motors at different speeds and checking whether the robot responded correctly. We also tested steering control by sending different steering angles and checking whether the wheels moved to the expected positions.

The sensor modules were tested separately as well. The ToF sensors were checked by printing distance values to the terminal. The gyroscope was tested by rotating the robot and checking whether the measured angle changed correctly. The camera system was tested by checking whether it could detect the correct colors and markings.

We also used logging and camera streaming during testing. Logging helped us review values after a test, while camera streaming allowed us to see what the robot was detecting in real time. This was especially useful for tuning color recognition, because lighting conditions can strongly affect camera-based detection. 

The main goal of software testing was to make sure that each part of the program worked before combining everything. This reduced the chance of hidden errors in the final system.

## System Testing

During system tests, we checked whether the robot could move, steer, read sensors, process camera data, and react correctly at the same time. We encountered several problems related to component communication, torque calculations, steerability, and sensor accuracy. The robot had to be reassembled and adjusted several times, but after multiple test cycles, the systems came together as a working unit.

---

| Test | Condition | Result | Improvement |
|---|---|---|---|
| Motor and battery heat test | Motors running continuously in ~35°C hall | Motors and battery survived, Raspberry Pi overheated without cooling | Added fan and cooling board |
| Lubrication test | WD-40 vs lithium grease on drivetrain | Lithium grease stayed longer and reduced friction better | Used lithium grease |
| Tire slip test | Small amount of water on wheels | Robot still moved, but odometry became less reliable | Use sensor feedback to correct movement |
| ToF lighting test | Indoor LED lighting vs sunlight | ToF sensors were more stable indoors | Calibrate under competition lighting |
| Gyro drift test | Robot standing still before run | Drift can build up over time | Gyro offset calibration at startup |

---

# Development Process

Our development process followed an iterative engineering cycle. Instead of trying to build the final robot in one step, we moved through several stages: planning, designing, building, testing, improving, and retesting. If a problem appeared during testing, we returned to an earlier stage and improved the design before moving forward again.

This process helped us avoid relying on assumptions. Each version of the robot gave us new information, and we used that information to make the next version better.

---

## 0. Brainstorming About Principles

The first step was brainstorming the main design principles of the robot. Before choosing exact parts or designing models, we discussed what the robot needed to achieve and what priorities should guide the whole project.

Our main principles were compact size, reliable movement, simple maintenance, accurate sensing, and strong mechanical stability. We wanted the robot to be as small as possible, but not at the cost of important functionality. This meant every component had to have a clear purpose and a logical position inside the robot.

We also considered which systems would be the most important for the challenges. These included steering, drivetrain efficiency, sensor placement, camera visibility, battery reliability, and software control. By defining these principles early, we had a clearer direction during the rest of the development.

---

## 1. CAD Design, Electronics Design, and Choosing Parts

After defining the main principles, we started designing the robot in CAD. This included both the mechanical 3D design and the layout of the electronic components.

For the mechanical CAD, we designed the chassis, steering system, drivetrain mounts, sensor mounts, Raspberry Pi mount, and other structural parts. The CAD model helped us check whether all components could fit together before printing or assembling anything.

We also planned the electronics layout. This included choosing where to place the Raspberry Pi, motor drivers, sensors, battery, wiring, and cooling system. Electronics placement was important because poor cable routing could cause reliability problems later.

At the same time, we chose the main components. We selected parts based on availability, size, documentation, compatibility, and how easily they could be integrated into our system. We tried to choose parts that were reliable but still simple enough to work with during development.

---

## 2. Checking Every Measurement

Before manufacturing or assembling parts, we checked all important measurements. This included component dimensions, hole spacing, rod distances, shaft positions, gear spacing, sensor angles, cable clearance, and mounting points.

This step was important because small measurement errors can cause major problems in a compact robot. A difference of one or two millimeters can decide whether a part fits, whether gears mesh correctly, or whether a sensor has a clear view.

We compared CAD dimensions with real component measurements whenever possible. Manufacturer datasheets were useful, but we also measured physical parts ourselves because real parts are not always exactly the same as their official drawings.

By checking measurements carefully, we reduced the number of failed prints and assembly problems.

---

## 3. 3D Printing and Assembly

After checking the design, we 3D printed the required parts and started assembly. This stage turned the CAD model into a real physical robot.

During assembly, we tested how well the printed parts fit with the metal rods, motors, gears, sensors, and electronics. Some parts fit correctly immediately, while others needed small adjustments. In some cases, we used filing, grinding, or sanding to make parts fit better. In other cases, we returned to CAD and changed the model.

Assembly also helped reveal problems that were not obvious in CAD. For example, a part might look correct digitally but be difficult to tighten, hard to access, or too close to wires or moving components. Because of this, assembly was not only a building step, but also another form of testing.

---

## 4. Testing and Returning to Step 0 if Necessary

After assembly, we tested the robot and its individual systems. This included mechanical testing, electronics testing, sensor testing, software testing, and full-system testing.

The goal of testing was to find weak points. We checked whether the robot could drive, steer, detect walls, recognize colors, read sensor data, and react correctly. We also tested the drivetrain, battery, cooling, and sensor accuracy.

If a major problem appeared, we returned to an earlier stage of the process. Sometimes this meant changing a CAD part, choosing a different component, changing the electronics layout, or rethinking the original design principle.

This made the process iterative. Testing was not the end of development; it was a way to collect information and improve the next version.

---

## 5. Looking for Improvements

Once the robot worked, we did not immediately consider it finished. Instead, we looked for possible improvements in every part of the system.

We checked whether the robot could be smaller, lighter, stronger, faster, easier to repair, or more reliable. We also looked at software improvements, such as better sensor processing, smoother steering correction, more stable camera recognition, and cleaner program structure.

This step was important because a working robot is not always an optimized robot. Even if the robot completes a task, small improvements can make it perform more consistently during competition.

We focused especially on parts that caused problems during testing, such as overheating, mechanical friction, sensor inaccuracies, or movement instability.

---

## 6. Making All Possible Improvements

After identifying possible improvements, we implemented as many of them as we realistically could. This included redesigning parts, improving mounts, adjusting tolerances, changing gear ratios, improving cooling, tuning sensor values, and refining software logic.

Some improvements were mechanical, such as making parts stronger or reducing friction. Others were electronic, such as improving cable management or cooling. Software improvements included better calibration, more reliable detection, and improved control behavior.

This step was about turning observations into real changes. Instead of only noting what could be better, we tried to physically improve the robot and then test whether the change actually helped.

---

## 7. Final Testing and Challenge Runs

After making improvements, we performed final system testing. This meant testing the robot as close to competition conditions as possible.

We ran the robot through the actual challenge tasks and checked whether it could perform reliably from start to finish. During these tests, we observed movement accuracy, sensor reactions, turning behavior, camera detection, battery performance, and overall consistency.

If the robot failed or showed a weakness, we returned to step 5 and looked for further improvements. This helped us refine the robot until it became more stable and competition-ready.

Final testing was important because a robot may work once, but competition requires repeatability. The robot needs to perform reliably multiple times, not only under perfect conditions.

---

## 8. Bringing It to Competition

The final step was preparing the robot for competition. At this point, the goal was not to make major experimental changes, but to make sure the robot was complete, reliable, and ready to run.

This included checking all screws, wires, printed parts, sensors, batteries, software files, and spare components. We also made sure the robot could be transported safely and assembled or repaired quickly if needed.

By the time we brought the robot to compete, it had already gone through multiple cycles of design, testing, improvement, and final validation. This gave us more confidence in the system, because the robot was not only designed theoretically, but tested and improved through real experience.

Overall, our development process was based on continuous iteration. Every test gave us feedback, every problem led to a design improvement, and every improvement brought the robot closer to a reliable final version.

---

# Version History / Iteration Log

| Version | Main issue | Change made | Result |
|---|---|---|---|
| V1: First drivetrain concept | No proper mounting system, poor gear fit, unsuitable 45:1 gear ratio, weak electronics mounting, and too small turning radius | First full redesign | Led to V2 |
| V2: First hexagonal mounting system | Steering mechanism was not centered, gears did not fit well, and sensor mounts caused issues | Redesigned the steering and sensor mounts | Led to V3 |
| V3: Second hexagonal mounting system | Gear fit was still unreliable, driveshaft was too low, gear ratios were unsuitable, and there was no battery mount | Completely redesigned the rear section and partially redesigned the front | Led to V4 |
| V4: Final design | Slightly too much friction in moving parts | Added lubricant and filed down moving parts | Competition version |

---

# Build Instructions

The build process of the robot follows a logical order: first the mechanical parts are manufactured, then the electronics are prepared, the components are mounted, the software is uploaded, and finally the whole system is tested. This order is important because each step depends on the previous one being completed correctly.

The general build process is:

1. 3D print the CAD files.
2. Solder and prepare the electronic components.
3. Mount the mechanical parts.
4. Install the electronics onto the chassis.
5. Upload the software to the onboard computer.
6. Configure, calibrate, and test the full system.

---

# CAD Files

The `models/` folder contains the CAD files for the main printable and manufacturable robot parts.

| Part | Purpose |
|---|---|
| Chassis- Drivetrain -Raspberry Pi - Battery mounts | Holds the two metal rods, and most of the components and form the base structure |
| Steering parts | Create the Ackermann steering mechanism |
| Sensor mounts | Hold the ToF sensors and camera in fixed positions |
---
## Hardware Assembly

The first step is to 3D print all custom CAD parts. These include the chassis mounts, drivetrain mounts, sensor mounts, Raspberry Pi mount, steering parts, and any other custom brackets used in the robot. After printing, the parts should be checked for defects, incorrect dimensions, weak layers, or rough surfaces.

Some printed parts may require small adjustments before assembly. This can include sanding, filing, drilling, or slightly widening holes. This is normal because 3D-printed parts are not always perfectly accurate, especially when tight tolerances are used.

After the printed parts are prepared, the mechanical structure can be assembled. The metal rods are used as the main chassis base, and the custom mounts are attached to them. The steering system, drivetrain, differential, gears, wheels, and driveshaft should be installed carefully, making sure that all moving parts rotate freely.

Once the mechanical parts are assembled, the electronics can be prepared. This includes soldering wires, connectors, motor driver connections, sensor cables, power connections, and any required headers. All solder joints should be checked to make sure they are strong and not shorted.

After soldering, the electronics are mounted onto the robot. The Raspberry Pi, motor driver, sensors, battery, camera, and wiring should be placed securely. Cable management is important because loose wires can touch moving parts, block the camera, or disconnect during movement.

---

## Software Installation

After the hardware is assembled, the software can be installed on the Raspberry Pi. The Raspberry Pi should have the required operating system installed and configured before uploading the robot code.

The repository should be copied onto the Raspberry Pi, usually through SSH. SSH allows the robot to be accessed remotely from another computer, so code can be uploaded and tested without connecting a monitor and keyboard directly to the robot.

The required Python libraries must be installed using the project’s setup files or requirements file. These libraries are needed for GPIO control, camera processing, sensor communication, motor control, and web streaming.

The software installation process includes:

1. Copying the project files to the Raspberry Pi.
2. Installing the required system packages.
3. Installing the Python dependencies.
4. Enabling required interfaces such as I²C, camera support, and PWM.
5. Checking that the main program can start without missing-library errors.

---

## Configuration

The Raspberry Pi configuration has to be checked. I²C must be enabled so the sensors can communicate with the Raspberry Pi. Camera support must be enabled so the Pi Camera can work. PWM configuration is also needed for reliable motor and servo control.

The camera color filters may also need adjustment depending on lighting conditions. HSV values for colors such as orange, blue, red, and green should be tuned so the robot detects the correct markings and objects.

Good configuration is important because even a correctly assembled robot can behave incorrectly if the software values do not match the real hardware.

---

## Calibration

Calibration improves the accuracy of the robot before testing or running the challenge. Since sensors and mechanical parts are never perfectly accurate, calibration helps reduce errors.

The gyroscope should be calibrated at startup while the robot is standing still. This allows the program to measure the sensor’s offset and reduce gyro drift. Drift is when the measured angle slowly changes even though the robot is not rotating.

The ToF distance sensors should also be checked using known distances. By comparing the measured values with real distances, the average error can be found and corrected in software.

The motor encoder should be calibrated by moving the robot a known distance and comparing it with the distance calculated by the software. This helps adjust the conversion factor between encoder ticks and centimeters.

The camera system should be calibrated by testing the color detection under the expected lighting conditions. If the camera does not recognize the correct colors, the HSV ranges should be adjusted.

Important calibration steps:

1. Keep the robot still and calibrate the gyroscope.
2. Test ToF sensors at known distances.
3. Check encoder distance calculation.
4. Tune HSV color filters for the camera.
5. Test steering center and maximum steering angles.
6. Confirm that the robot reacts correctly to sensor input.

---

## Testing

After assembly, installation, configuration, and calibration, the robot must be tested. Testing should start with individual components, then move to full-system tests.

First, the motors and steering should be tested separately. Then the sensors should be tested one by one. The camera stream should also be checked to confirm that the robot sees the track correctly.

After individual tests, the complete robot should be tested as one system. During this stage, the robot should be able to move, steer, read sensors, process camera data, and react correctly at the same time.

If problems appear during testing, the build process may return to an earlier step. For example, a mechanical issue may require redesigning or reprinting a part, while a sensor issue may require recalibration or software changes.

The final goal of testing is to confirm that the robot is reliable, repeatable, and ready for challenge runs.

## Rejected design choices

| Option considered  | Why we rejected it | Final choice |
| --- | --- | --- |
| Larger chassis | Easier wiring, but worse turning and less margin  | Compact chassis |
| 1:1.5 gear ratio | Too little torque, motor could not start reliably | ~1:6 reduction |
| Ultrasonic sensors | Larger, slower, less precise at short range | ToF sensors |
| No cooling | Pi overheated during long tests | Fan + cooling board |
| Skid steering | Less realistic, more slip | Ackermann steering  |

---

## Points of failure /  Risk analysis table

| Risk | Cause | Effect | Prevention / solution |
| --- | --- | --- | --- |
| Raspberry Pi overheating | High CPU load + no cooling | Camera/control crash  | Fan and cooling board |
| Gyro drift | IMU offset accumulates | Wrong heading | Startup calibration |
| Wheel slip | Low traction surface | Bad odometry | ToF + camera correction |
| ToF false reading | Sunlight/reflection | Wrong wall distance | Indoor calibration + sensor fusion |
| Camera color error | Lighting changes | Wrong block detection | HSV tuner |
| Gear friction | 3D printed drivetrain | Power loss / heating  | Lubrication + filing |

---
# Repository Structure

```text
WRO_26_FE_FRT_neoncso/
│
├── README.md
├── .gitignore
│
├── models/
│   └── 3D models and manufacturing files for printed or machined robot parts
│
├── other/
│   └── Additional technical documentation and supporting files
│
├── schemes/
│   └── Wiring diagrams and electronic connection schemes
│
├── t-photos/
│   └── Team photos required for the WRO documentation
│
├── v-photos/
│   └── Vehicle photos from different angles
│
├── video/
│   └── Driving demonstration video link or video documentation
│
└── src/
    │
    ├── README.md
    ├── __init__.py
    ├── 99-wro.rules
    ├── config.py
    ├── config.txt
    ├── open.py
    ├── obstacle.py
    ├── test.py
    ├── setup.py
    ├── setup.sh
    ├── start.sh
    ├── requirements.txt
    │
    └── utils/
        │
        ├── hsv_tuner/
        │   └── HSV color calibration tools
        │
        ├── gyro.py
        ├── image_proc.py
        ├── log.py
        ├── movement.py
        ├── stream.py
        └── tof.py
```

---

# Media

## Robot Photos

Robot photos from different angles are included in the `v-photos/` folder.

## Team Photos

Team photos are included in the `t-photos/` folder.

## Videos

Driving demonstration videos are included in the `video/` folder.

- Open Challenge video: `video/open_challenge`
- Obstacle Challenge video: `video/obstacle_challenge`

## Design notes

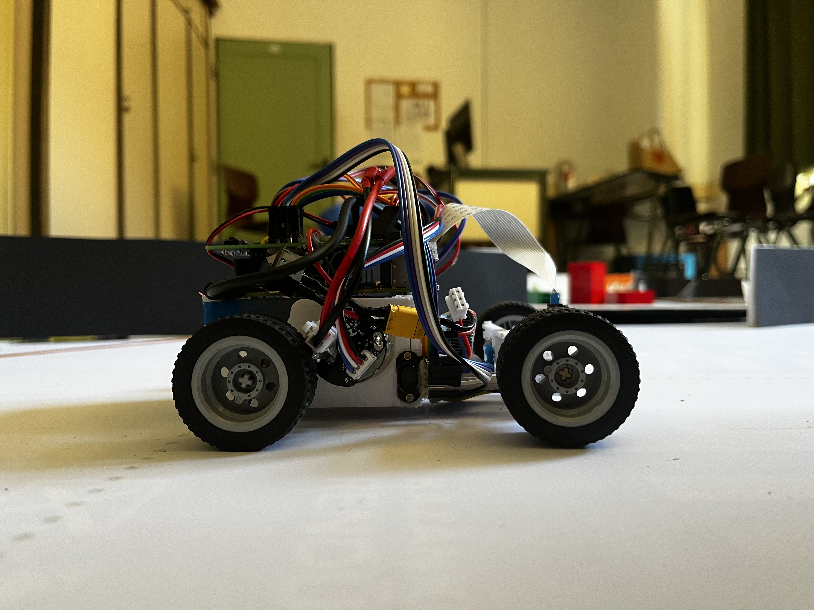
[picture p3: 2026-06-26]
v-photos/right side.jpeg

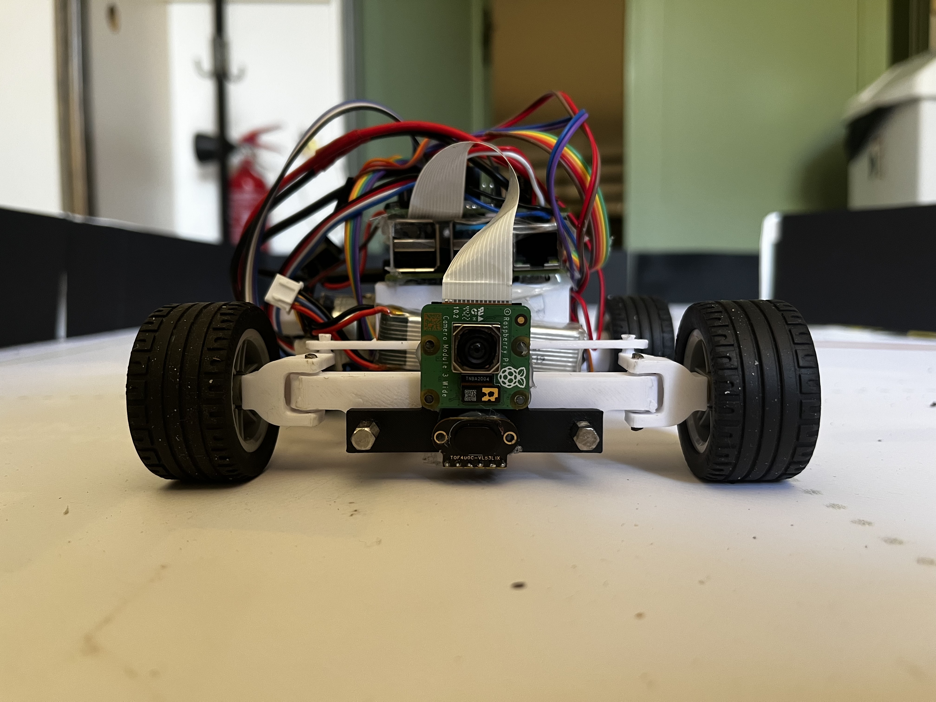
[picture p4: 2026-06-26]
v-photos/front.jpeg

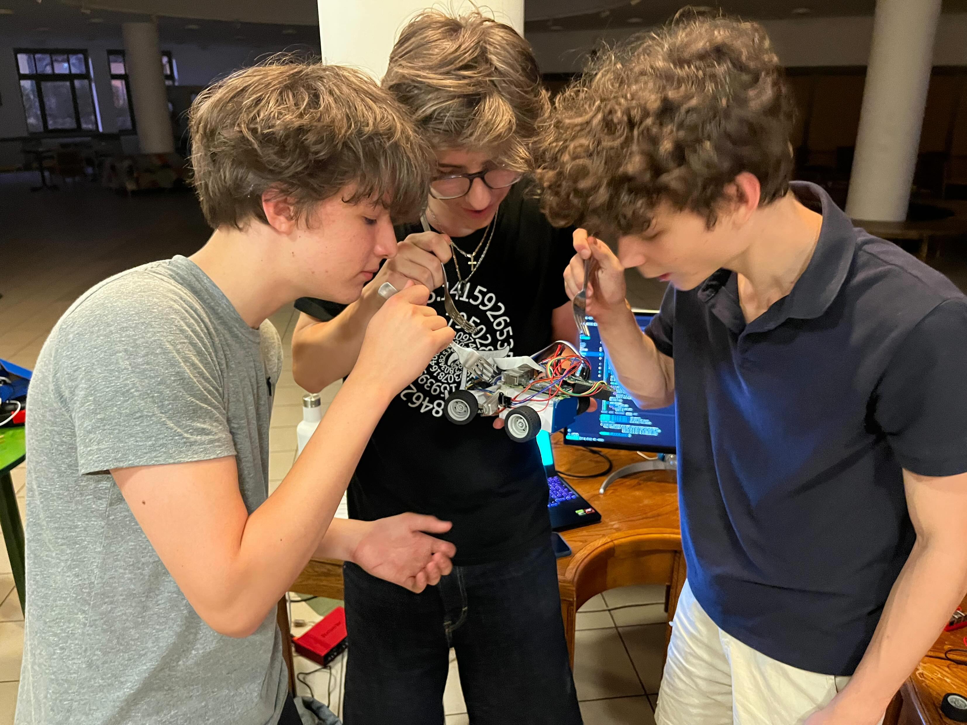
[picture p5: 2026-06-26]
t-photos/Funny.jpg

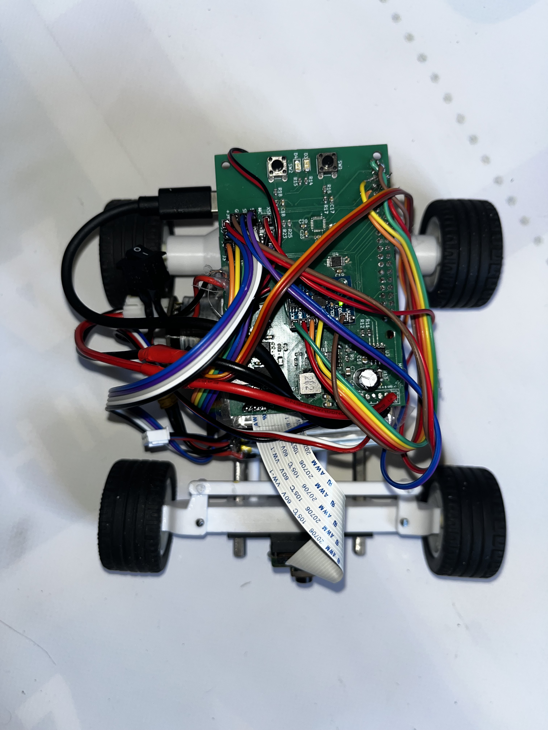
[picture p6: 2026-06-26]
v-photos/top.jpeg

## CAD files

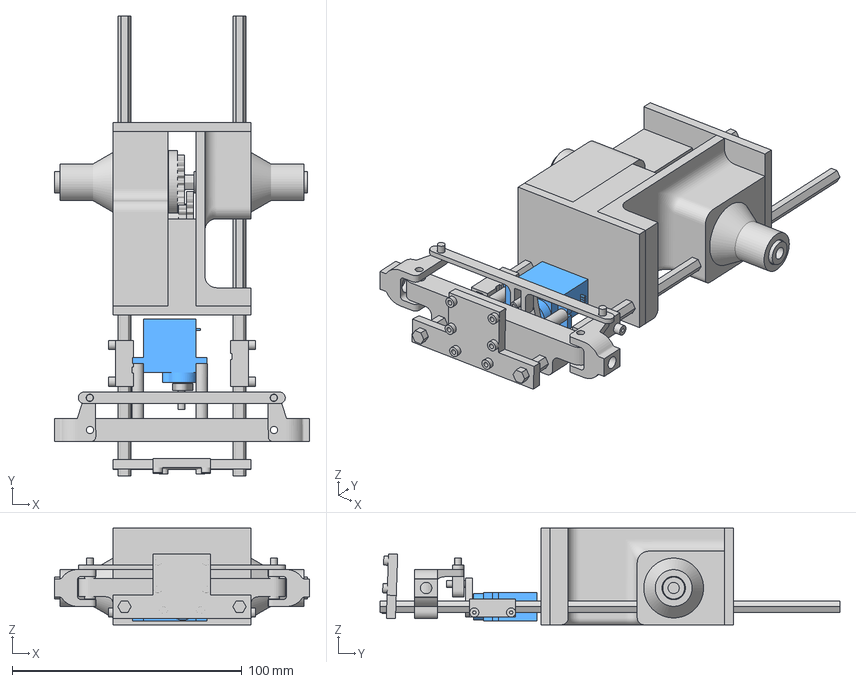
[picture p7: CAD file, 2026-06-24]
models/assembly.3mf
111.0 x 200.0 x 42.0 mm
double gear (1)
double gear
front plate
front wheel mount
gearbox
large gear
link left
link right
main steering body
motor and diff casing part 1
motor and diff casing part 2
plate1
plate2
rod x 2
servo arm
small gear
steering linkage
tof mount x 2

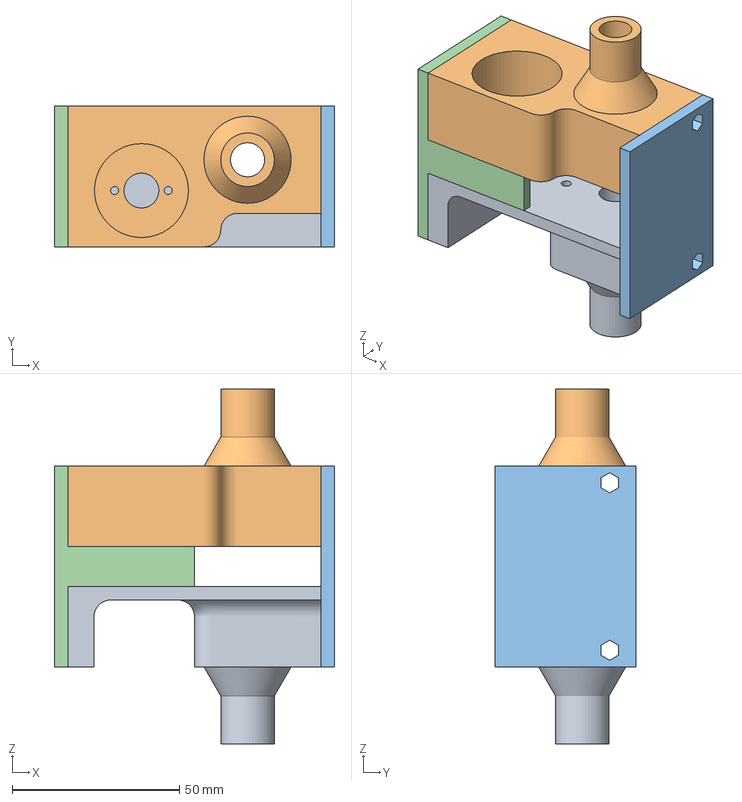
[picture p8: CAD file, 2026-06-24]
models/motor and differential casing.3mf
83.7 x 42.0 x 106.0 mm
motor and diff casing part 1
motor and diff casing part 2
plate1
plate2

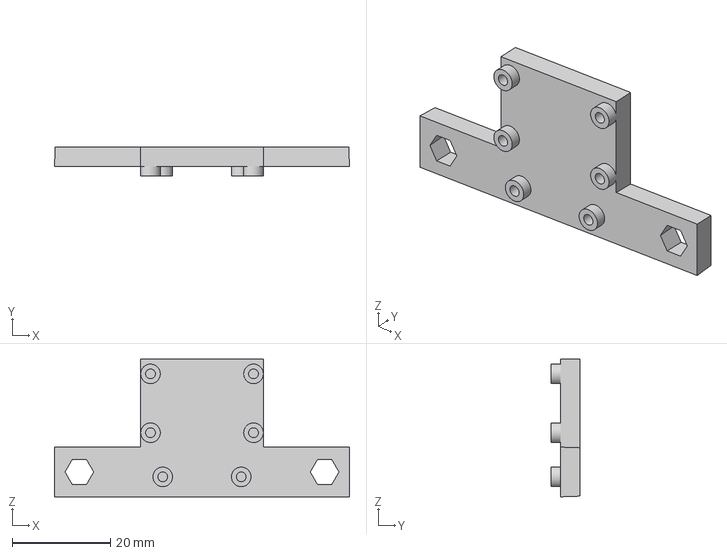
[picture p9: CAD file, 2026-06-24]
models/cam and tof holder.3mf
60.1 x 6.00 x 28.1 mm

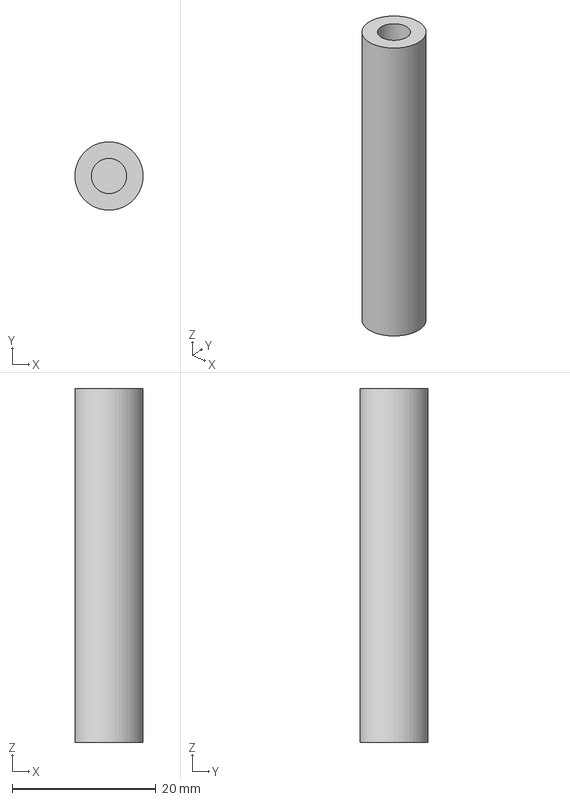
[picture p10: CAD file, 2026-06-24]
models/link piece.3mf
9.50 x 9.48 x 49.2 mm

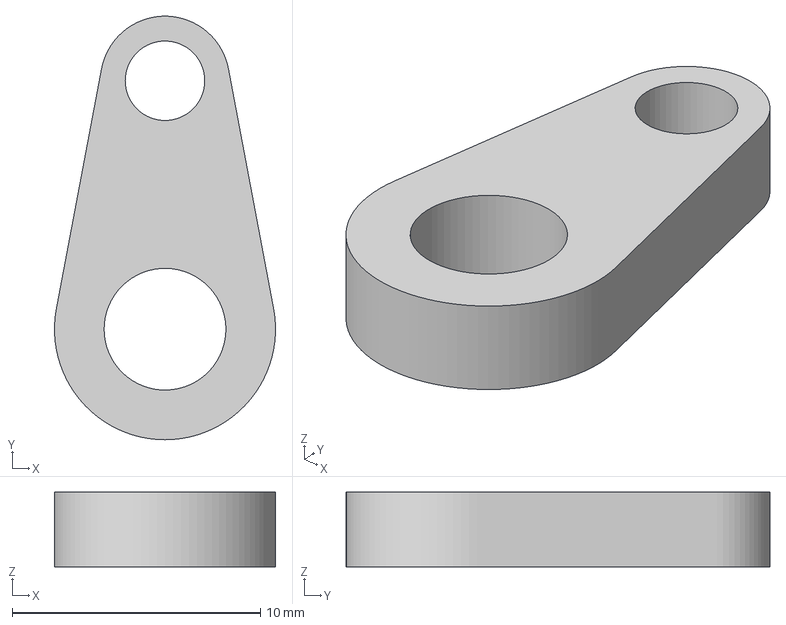
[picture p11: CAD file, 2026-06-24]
models/servo_arm.3mf
8.89 x 17.0 x 3.00 mm

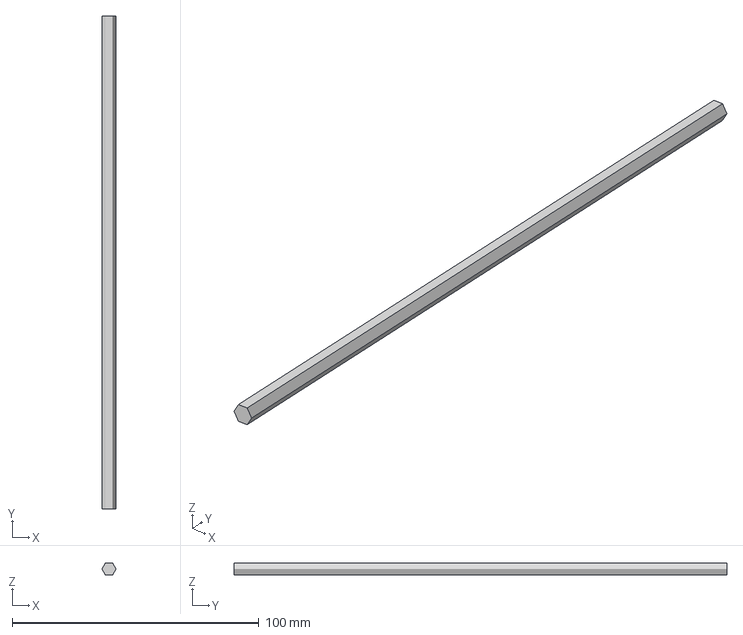
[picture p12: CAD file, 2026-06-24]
models/connecting rod bottom.3mf
5.77 x 200.0 x 5.00 mm

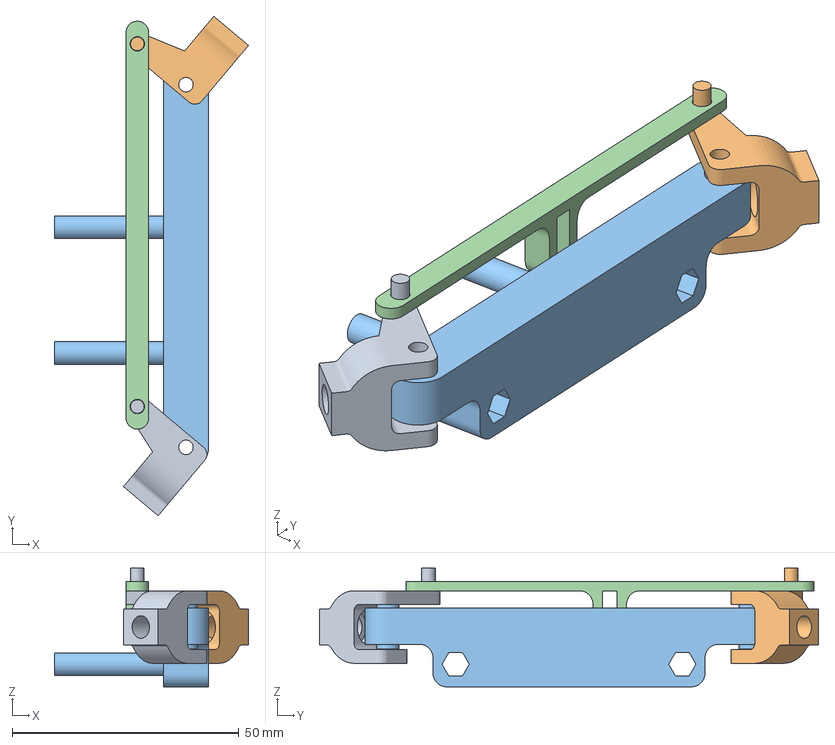
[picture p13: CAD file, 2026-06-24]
models/steering_mechanism.3mf
42.8 x 110.2 x 26.2 mm
front wheel mount
main steering body
steering linkage

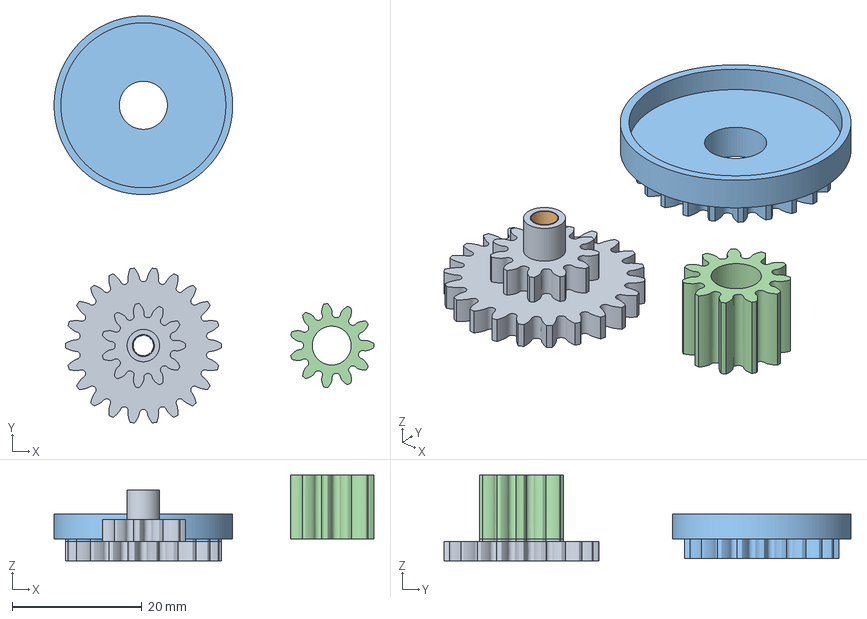
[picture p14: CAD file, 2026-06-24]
models/gears.3mf
49.2 x 62.7 x 13.2 mm
double gear (1)
double gear
large gear
small gear

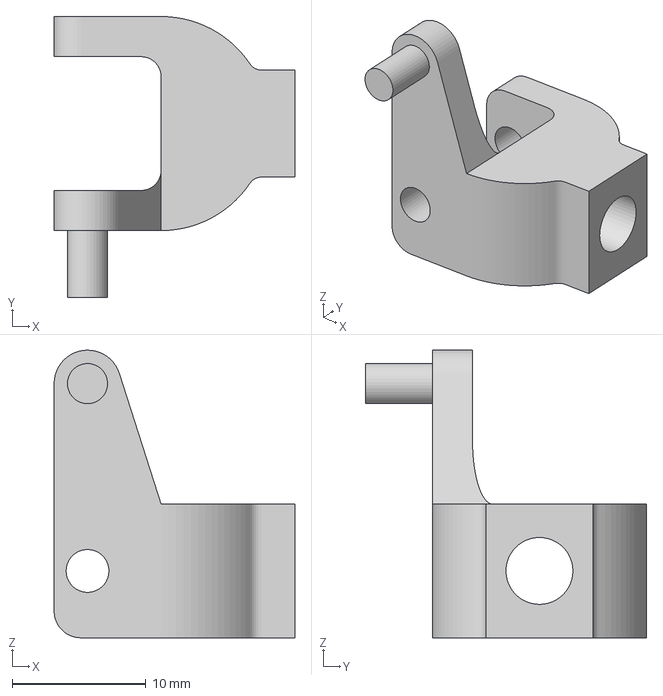
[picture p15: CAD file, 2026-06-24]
models/front wheel mount.3mf
18.0 x 21.0 x 21.5 mm

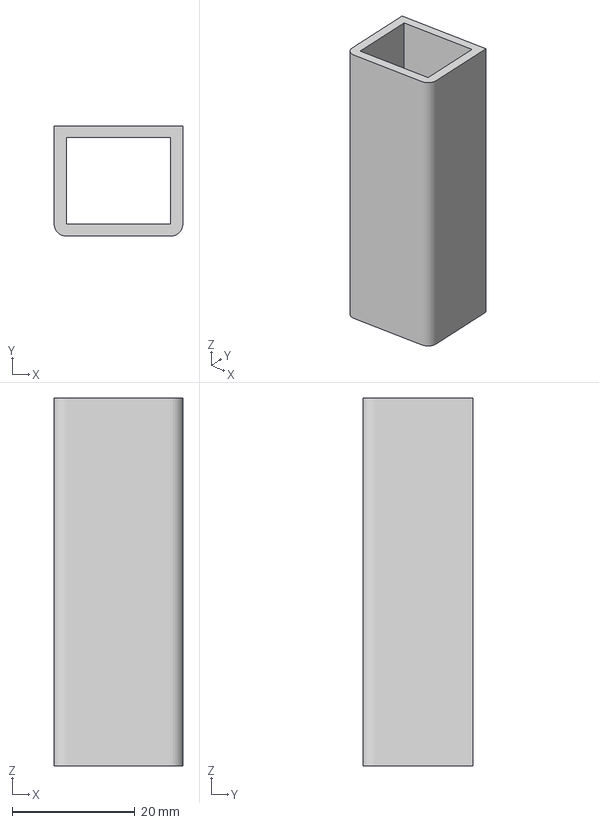
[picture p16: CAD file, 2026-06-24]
models/battery_holder.3mf
21.0 x 18.0 x 60.0 mm

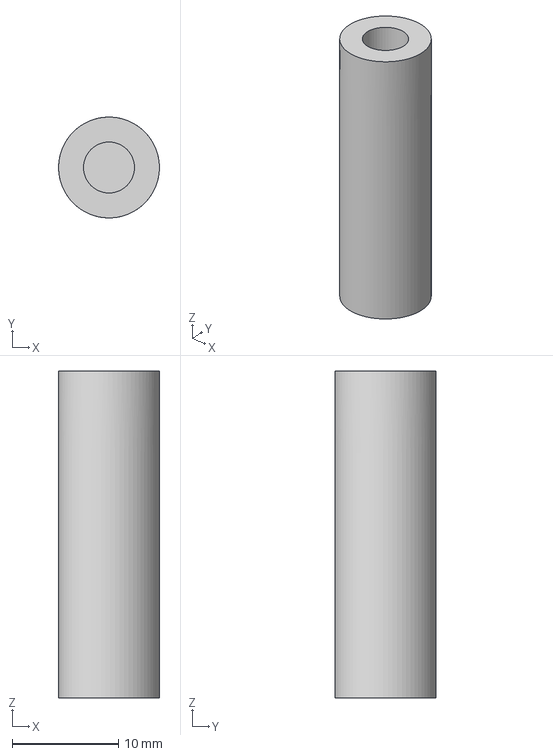
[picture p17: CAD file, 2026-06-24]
models/link piece right.3mf
9.50 x 9.50 x 30.8 mm

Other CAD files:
models/battery_holder.f3d
models/cam and tof holder.f3d
models/connecting rod bottom.f3d
models/front wheel mount.f3d
models/gears.f3d
models/link piece right.f3d
models/link piece.f3d
models/motor and differential casing.f3d
models/servo arm.f3d
models/steering_mechanism.f3z

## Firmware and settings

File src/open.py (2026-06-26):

import time
import config as conf
from utils.gyro import Gyro 
import utils.image_proc as cam
import utils.log as log
import utils.stream as stream
import utils.movement as move
import cv2
import RPi.GPIO as GPIO
from utils import tof

gyro = None

SPEED = 30
MAX_STEER = 45
STEER_SIGN = 1
HSIGN = 1

KP_HEADING = 1.6
KD_HEADING = 0.3
KI_CENTERING = 0.01
I_LIMIT = 20.0

MAX_STRAIGHT_DEGREE = 20 # maximum degree for integrating centering (I component)
FRONT_TOF_CORNER_DISTANCE = 450 
FRONT_CLEAR = 750 #above this limit the corner detection with the front tof reactivates
CORNERS = 12

def turn():
    current_angle = gyro.get()
    target_angle = 0
    if move.turning_direction == "left":
        target_angle = current_angle -90
        move.set_angle(-70)
        while not current_angle <= target_angle:
            move.set_speed(50)
        move.set_speed(0)
    elif move.turning_direction == "right":
        target_angle = current_angle +90
        move.set_angle(70)
        while not current_angle >= target_angle:
            move.set_speed(50)
        move.set_speed(0)
turning_direction = None
def move_until_line(speed, required_count):
    global turning_direction
    
    blue_count = 0
    orange_count = 0

    while orange_count < required_count or blue_count < required_count:

        direction = cam.get_direction()
        if direction == "orange":
            orange_count += 1
        elif direction == "blue":
            blue_count +=1

    if orange_count >= 5:
        turning_direction = "right"
        return True
    elif blue_count >= 5:
        turning_direction = "left"
        return True

    return False

def main():
    GPIO.setmode(GPIO.BCM)
    GPIO.setup(conf.BTN_1, GPIO.IN)
    GPIO.wait_for_edge(conf.BTN_1, GPIO.FALLING)

    gyro = Gyro(conf.GYRO_ADDR)
    move.setup(gyro)
    tof.setup()
    cam.setup()
    gyro.reset()

    target = 0.0
    corners = 0

    front = tof.get_front()



    move.move(100, 5, True, move_until_line)
    move.move(50, 100,False)
    turn()
    

    """

    i_center = 0.0

    i_max = I_LIMIT / KI_CENTERING   #clamping the I component at a max value

    prev_t = time.time()


    
    while corners < CORNERS:
        now = time.time()
        dt = now - prev_t
        prev_t = now

        

        tof_right = tof.get_front()
        tof_left = tof.get_left()
        tof_front = tof.get_front()

        err = target - gyro.get()
        rate = gyro.read_gyro()["z"]

        if tof_left is not None and tof_right is not None and abs(err) < MAX_STRAIGHT_DEGREE:
            i_center += (tof_left - tof_right) * dt
            i_center = max(-i_max, min(i_max, i_center))
        
        s = HSIGN * (KP_HEADING * err - KD_HEADING * rate) + KI_CENTERING * i_center
        move.set_angle(max(-MAX_STEER, min(MAX_STEER, s)))
        move.set_speed(SPEED)

        if not near and tof_front is not None and tof_front < FRONT_TOF_CORNER_DISTANCE:
            near = True
            if turn_left is None:
                turn_left = (tof_left or 0)

                target += (90 if turn_left else -90) * HSIGN
                corners +=1
            elif near and (tof_front is None or tof_front >FRONT_CLEAR):
                near = False
            time.sleep(0.01)
        """
def cleanup():
    gyro.kill()
    cam.kill()
    move.cleanup()


if __name__ == "__main__":
    try:
        main()
    except KeyboardInterrupt:
        cleanup()

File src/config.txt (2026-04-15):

# For more options and information see
# http://rptl.io/configtxt
# Some settings may impact device functionality. See link above for details

# Uncomment some or all of these to enable the optional hardware interfaces
dtparam=i2c_arm=on
#dtparam=i2s=on
#dtparam=spi=on

# Enable audio (loads snd_bcm2835)
dtparam=audio=on

# Additional overlays and parameters are documented
# /boot/firmware/overlays/README

# Automatically load overlays for detected cameras
camera_auto_detect=1

# Automatically load overlays for detected DSI displays
display_auto_detect=1

# Automatically load initramfs files, if found
auto_initramfs=1

# Enable DRM VC4 V3D driver
dtoverlay=vc4-kms-v3d,cma=256M
max_framebuffers=2

# Don't have the firmware create an initial video= setting in cmdline.txt.
# Use the kernel's default instead.
disable_fw_kms_setup=1

# Run in 64-bit mode
arm_64bit=1

# Disable compensation for displays with overscan
disable_overscan=1

# Run as fast as firmware / board allows
arm_boost=1

dtoverlay=pwm-2chan,pin=12,func=4,pin2=13,func2=4
lcm4]
# Enable host mode on the 2711 built-in XHCI USB controller.
# This line should be removed if the legacy DWC2 controller is required
# (e.g. for USB device mode) or if USB support is not required.
otg_mode=1

[cm5]
dtoverlay=dwc2,dr_mode=host

[all]

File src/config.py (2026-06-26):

import math

LOG_PATH = "./logs"
LOG_LEVEL = "DEBUG"

GYRO_ADDR = 0x69

TOF_SHUT_1 = 17
TOF_SHUT_2 = 27
TOF_SHUT_3 = 22

MS_PER_MEASURE = 200
MEASURE_DENSITY = 250
POLL_PERIOD = 0.005

M_PWM_1 = 23
M_PWM_2 = 24

M_ENC_A = 8
M_ENC_B = 7
M_ENC_FACTOR = -((42 * math.pi) / 6) * 0.758

BTN_1 = 5
BTN_2 = 6

LED_R = 19
LED_G = 26


HSV_FILTERS = {
    "orange":  {
        "lower": [2, 41, 129],
        "upper": [13, 255, 255],
    },
    "red": {
        "lower": [172, 138, 56],
        "upper": [179, 255, 255],
    },
    "blue": {
        "lower": [110, 52, 55],
        "upper": [130, 255, 255]
    },
    "green": {"lower": [  0, 20,  50], "upper": [ 10, 255, 255]},
    "magenta":{"lower": [150, 10,  10], "upper": [179, 255, 255]},
}

BLOCK_TRSH = 30

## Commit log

2026-06-24 Uploaded 3d modells
    The files are fusion archive files, and can be opened with Fusion 360.
    [battery_holder.f3d, cam and tof holder.f3d, connecting rod bottom.f3d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]
2026-06-24 Different file extension
    [assembly.3mf, battery_holder.3mf, cam and tof holder.3mf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]
